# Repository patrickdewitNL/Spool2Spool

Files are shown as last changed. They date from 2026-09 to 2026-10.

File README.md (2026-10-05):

# Spool2Spool Controller

Dual-motor arm/tension controller: an ESP-WROOM-32 devkit driving two 24V geared DC motors
through BTS7960/IBT-2 drivers, with an I2C LCD for local readout/control and a separate
Wemos D1 mini node reading the arm angle right at the pivot.

## What it does

- **Motor 2** has the only encoder (hall sensor/pulse feedback) in the system: closed loop
  constant speed control, targeting a speed in m/min (converted to RPM using the spool
  diameter). Pot 2 sets this target continuously in auto mode, and drives the PWM directly
  (open loop) in manual mode — same knob, different meaning depending on mode. A
  proportional controller corrects the PWM duty once per second.
- **Motor 1** has no encoder of its own. Its baseline PWM continuously tracks motor 2's PWM,
  keeping both motors nominally speed-matched, then gets a small proportional trim based on
  the arm's angle to hold that angle at a live-adjustable target. The angle itself is measured
  by an AS5600 magnetic sensor mounted right at the arm pivot, read by a separate Wemos D1
  mini, and pushed to the ESP32 over a one-way serial link — see
  [Wemos D1 mini angle-sensor node](#wemos-d1-mini-angle-sensor-node) below. The angle trim is
  deliberately small (capped, see `angleTrimLimitPWM`) so a noisy reading right at startup
  can only nudge motor 1 a little, never throw it far from motor 2's PWM. If motor 2's PWM
  is 0 (e.g. a 0 m/min setpoint), motor 1 forces to 0 as well regardless of angle error —
  the trim never applies on top of a stopped motor 2.
- Both motors support **manual override**, driving speed directly from a potentiometer instead
  of the automatic logic.
- Both motor outputs stay at **zero on power-up** until SELECT is pressed once.
- Local UI: LEFT/RIGHT toggle manual/auto mode per motor. A short SELECT press starts the
  system, then (once started) cycles which value UP/DOWN adjusts: spool diameter, then motor
  1's target angle — a transient screen shows the selected value and its new setting each time
  it changes. Motor 2's target speed isn't in this cycle; pot 2 sets that continuously instead
  (see above). Holding SELECT for ~1s while running **stops both motors** and re-arms the start
  interlock (release and press again to restart) — a software convenience stop, not a
  substitute for a real hardware emergency stop, see
  [Machine Directive / CE compliance](#machine-directive--ce-compliance) below. The 20x4 I2C
  LCD otherwise shows a "press SELECT to start" prompt, then live speed/mode2 on the top two
  lines and angle/mode1 on the bottom two.

## Hardware

- ESP-WROOM-32 devkit (30-pin), 3.3V logic throughout
  - ESP mounted using https://www.printables.com/model/1590288-esp32-wroom-32-din-rail-mounting-adapter and https://www.printables.com/model/472505-din-rail-bracket-redux/files
- 20x4 I2C LCD (PCF8574-based backpack, address 0x27)
- 5 discrete pushbuttons (LEFT/RIGHT/UP/DOWN/SELECT), each to GND, using the ESP32's internal
  pull-ups — no external resistors, no resistor-ladder shield
- 2x 24V geared DC motors, each driven through a BTS7960/IBT-2 module (PWM speed control only,
  R_EN/L_EN tied high in hardware, no direction control needed)
- Hall sensor/encoder on motor 2's shaft, 1 pulse per revolution, interrupt driven — the
  only encoder in the system; motor 1 has none
- 2x potentiometers: pot 1 is motor 1's manual PWM override; pot 2 is motor 2's manual PWM
  override in manual mode, and its target speed setpoint in auto mode
- A separate **Wemos D1 mini + AS5600** node mounted at the arm pivot, sending the angle over
  a serial link (see below) — no angle sensor lives on the ESP32 board itself

### EMI

This setup has visible susceptibility to electrical noise, most likely from the BTS7960
drivers' PWM switching and/or from switching on the 230V/24V supply itself:

- Plugging in the 230V/24V supply while the LCD is on has been observed to garble it. The
  firmware now periodically re-inits the LCD controller (`lcdReinitIntervalMs`, every 30s) as
  self-recovery, since a glitch on SDA/SCL can corrupt the PCF8574 backpack's internal state in
  a way plain `lcd.print()` calls don't fix.
- The hall sensor/encoder has shown phantom pulses (read as an implausibly high speed, which
  then yanks motor 2's PWM down hard) — mitigated firmware-side with a debounce
  (`minPulseIntervalMicros`) that drops edges arriving faster than any real pulse could.
- Neither of these firmware mitigations addresses the noise at its source. If it persists,
  hardware measures worth trying: a small RC low-pass filter right at the hall sensor output,
  twisted-pair/shielded wiring for the sensor and I2C runs routed away from the motor power
  leads, decoupling capacitors across the LCD backpack's and BTS7960 modules' supply pins, and
  a proper single-point (star) ground / PE bond for the enclosure.

## Machine Directive / CE compliance

This has two motorized moving parts (the arm and the spools) that can pinch or entangle, which
puts it in scope of the Machine Directive (2006/42/EC — being replaced by Machinery Regulation
(EU) 2023/1230, applicable from January 2027) if it's ever placed on the market rather than kept
as a one-off bench setup. It is **not** currently compliant. The main gap:

- **No emergency stop.** EN ISO 13850 / EN 60204-1 §9.2.5.4 require a readily-accessible
  emergency-stop device (red mushroom-head pushbutton, yellow background, latching/pull-to-release)
  on any machine with a hazard like this. Critically, it must cut power to both motors **in
  hardware** — wired in series with the 24V supply to the BTS7960 drivers (or through a safety
  relay/contactor), not just wired into a GPIO for the firmware to react to. A software-only stop
  (e.g. an E-stop button read like the existing LEFT/RIGHT/UP/DOWN/SELECT buttons, forcing
  `motor1PWM`/`motor2PWM` to 0) doesn't satisfy this: it stops working the moment the ESP32 hangs,
  crashes, is mid-OTA-update, or has a firmware bug — exactly when a hardware stop is needed most.
- This should be a **Category 0 stop** per EN 60204-1 §9.2.2 (immediate removal of power to the
  actuators) — simplest to implement here since these are plain DC motors with no regenerative
  braking or controlled-deceleration requirement.
- After an E-stop trip, the machine must **not** restart on its own when the button is released —
  it needs a deliberate manual reset (e.g. releasing the latch, then pressing SELECT again to
  restart, same as the existing power-up interlock already does).
- The E-stop's own monitoring/status wiring, if any, is the one case in this project's wiring
  where **orange** (EN 60204-1's color for circuits that stay energized with the main switch off)
  would actually apply, rather than the blue used for the ordinary control signals in the tables
  below.

Beyond the E-stop, a full CE Declaration of Conformity would also need a documented risk
assessment (EN ISO 12100) covering the arm/spool pinch points and the other Annex I essential
health and safety requirements — worth doing before this leaves the bench, not just the E-stop
wiring in isolation.

## Pin mapping

| ESP32 pin | Function | Cable color in cabinet | Suggested color (EN 60204-1) |
|---|---|---|---|
| GPIO21 | I2C SDA — LCD | yellow | blue |
| GPIO22 | I2C SCL — LCD | green  | blue |
| GPIO16 | Serial2 RX — angle data in, from the Wemos D1 mini's TX | brown | blue |
| GPIO17 | Serial2 TX — connected to Wemos, not used |  | blue |
| GPIO25 | Motor 1 PWM output (no encoder — tracks motor 2's PWM + arm-angle trim) |  | blue |
| GPIO26 | Motor 2 PWM output (closed loop, driven by the encoder below) |  | blue |
| GPIO4  | Hall sensor / encoder pulse input (interrupt) — measures motor 2's shaft |  | blue |
| GPIO34 | Motor 1 manual override potentiometer (ADC1-only pin) |  | blue |
| GPIO35 | Motor 2 potentiometer — manual override PWM, or target speed setpoint in auto mode (ADC1-only pin) |  | blue |
| GPIO13 | Button: LEFT |  | blue |
| GPIO27 | Button: RIGHT |  | blue |
| GPIO32 | Button: UP |  | blue |
| GPIO33 | Button: DOWN |  | blue |
| GPIO14 | Button: SELECT |  | blue |

Every row above is a DC control-circuit conductor (logic-level signal, not a power feed), which
is why EN 60204-1 puts all of them under the same color — **blue**. The standard reserves other
colors for different roles: **black** for DC/AC power circuit conductors (the +3.3V/5V/GND
supply rails, not any row in this table), **green/yellow** exclusively for the protective earth
(PE) conductor bonded to the enclosure/frame (distinct from logic GND — see the note below), and
**orange** specifically for circuits that must stay energized when the main isolator is off, e.g.
an emergency-stop monitoring loop (see [Machine Directive / CE compliance](#machine-directive--ce-compliance)
below).

Red is always + 3.3V, Black is always GND. Blue is used for 5V from the ESP. Note this cabinet
convention doesn't itself follow EN 60204-1 (which reserves black for power circuits generally,
not GND specifically, and blue for DC control circuits, not a 5V supply feed) — it predates
adding the column above and hasn't been reconciled with it yet.

## Wemos D1 mini angle-sensor node

Firmware: [`software/WemosAngleSensor/WemosAngleSensor.ino`](software/WemosAngleSensor/WemosAngleSensor.ino) —
**finalized**. Reads an AS5600 magnetic angle sensor continuously and sends a line (e.g.
`"123.4\n"`) over its hardware serial only when the angle has moved more than 1 degree since
the last one sent. Purely one-way (Wemos -> ESP32), 9600 baud — nothing is requested or read
back, and the ESP32 side (`software/spool2spool-esp32`) just listens on Serial2 (GPIO16) and
keeps the last value it received.

| Wemos pin | Function | Cable color | Suggested color (EN 60204-1) |
|---|---|---|---|
| D1 (GPIO5) | AS5600 SCL |  | blue (DC control circuit) |
| D2 (GPIO4) | AS5600 SDA |  | blue (DC control circuit) |
| TX | Data out, to the ESP32's GPIO16 (Serial2 RX) |  | blue (DC control circuit) |
| 5V | Power in, from the ESP32 devkit's 5V/VIN pin |  | black (DC power circuit) |
| 3V3 | Powers the AS5600 — not the incoming 5V, keeps the sensor on the same 3.3V rail as the I2C logic |  | black (DC power circuit) |
| GND | Common ground, shared with the ESP32 and the cable shield |  | black (power circuit return — only use green/yellow if this conductor is actually bonded to protective earth, not for a floating logic GND) |

The AS5600's DIR pin ties to GND (or VCC — either works, just don't leave it floating); GPO is
unused since only I2C is needed here.

Cable: simple 4-conductor wire for the ~1.5m run to the arm — one conductor for data, one for
power, one for GND, 1x TX one time RX.

## Libraries

- `Wire.h` — built in
- `LiquidCrystal_I2C` — install via the Arduino Library Manager ("LiquidCrystal I2C"); needs
  a `begin(cols, rows)` variant, e.g. the DFRobot/Marco Schwartz-style fork most Library
  Manager searches return (the WARNING about it claiming "all architectures" is expected and
  harmless on ESP32)
- `WiFi.h`, `WebServer.h` — built in (ESP32 core); back the WiFi dashboard/OTA feature below
- `ElegantOTA` by Ayush Sharma — install via the Arduino Library Manager ("ElegantOTA"); serves
  the browser-based firmware-update page
- `AS5600` by Rob Tillaart — install via the Arduino Library Manager, needed only for the
  **Wemos** sketch, not the ESP32 sketch

## WiFi dashboard & OTA firmware updates

Once the board runs off an external 5V supply instead of USB (see the header comment in
`spool2spool-esp32.ino` for the full rationale), the only way back in is over WiFi:

- **Before flashing**, fill in `wifiSsid`/`wifiPassword` near the top of
  `spool2spool-esp32.ino`. Connecting is best-effort and bounded (10s) — a missing or slow
  network never blocks motor control.
- **Dashboard**: `http://<device-ip>/` mirrors the LCD (live speed/angle, their setpoints,
  motor 1/2 drive % and mode) plus a live graph of speed/angle vs. their setpoints. Graph
  history lives in the *browser's* `localStorage`, not on the ESP32 — it only covers however
  long that tab has been open/polling, isn't shared between browsers/devices, and has a
  "Clear graph history" button to purge it. The graph pulls in Chart.js from a CDN, so the
  *browser* needs internet access to render it (the ESP32 itself only needs the local network).
- **Firmware updates**: `http://<device-ip>/update` (ElegantOTA), also linked as a button from
  the dashboard. Because this is a browser-based updater rather than `ArduinoOTA`, the Arduino
  IDE's own Upload button won't find it as a network port — instead use **Sketch → Export
  Compiled Binary** (compiles without trying to upload anywhere) to produce a `.bin` in the
  sketch folder, then upload that file through the `/update` page.
- **AP fallback**: if the configured network isn't reachable at boot, the ESP32 hosts its own
  access point instead (`Spool2Spool-Setup` / `spool2spool` — change the password in the
  sketch), so the dashboard/OTA page is still reachable at `http://192.168.4.1` even out in the
  field with no WiFi around. This only happens once, at boot — it stays on the fallback AP
  until rebooted, it doesn't keep retrying the configured network in the background.

## Building / flashing

**ESP32 main controller**: open
[`software/spool2spool-esp32/spool2spool-esp32.ino`](software/spool2spool-esp32/spool2spool-esp32.ino)
in the Arduino IDE, select an ESP32 Dev Module board (arduino-esp32 core 3.x — needed for
`analogWrite()` support), install `LiquidCrystal_I2C` and `ElegantOTA`, fill in
`wifiSsid`/`wifiPassword` (see [WiFi dashboard & OTA firmware updates](#wifi-dashboard--ota-firmware-updates)
above), and upload over USB. After this first flash, further updates can go out over OTA
instead — USB is only required once.

**Wemos angle-sensor node**: open
[`software/WemosAngleSensor/WemosAngleSensor.ino`](software/WemosAngleSensor/WemosAngleSensor.ino),
select a Wemos D1 mini (ESP8266) board, install `AS5600`, and upload.

## Configuration

A handful of constants at the top of `spool2spool-esp32.ino` are meant to be tuned on the bench:

- `targetSpeedMPM` — motor 2's target speed in m/min, set continuously from pot 2 while in
  auto mode (see "What it does" above); the value at declaration is just a fallback default
- `Kp` — motor 2's speed-loop gain, currently 4.0. Named `Kp` but functionally an *integral*
  gain: the loop accumulates `Kp * error / 10` into the PWM every cycle rather than setting the
  PWM fresh from the current error each time, so it drives steady-state error to zero given
  enough cycles, at the cost of a slower initial response than true proportional control would
  give — still just a starting guess, keep tuning on the bench
- `maxMotor2PwmStepPerCycle` — caps how much the integral term above can move motor 2's PWM in
  a single ~1s cycle, in either direction. Without this, a big fresh error (e.g. at startup:
  target speed vs. actual 0) integrates into a near-instant slam to a high PWM before the
  motor/spool can physically respond — this smooths that into a gradual ramp instead. Doesn't
  affect the SELECT long-press stop or a real emergency stop, both of which cut power directly
  rather than ramping down through this loop
- `maxSetpointRampMPMPerCycle` — separate from the PWM-side cap above: slews the *setpoint*
  actually fed into the control loop's error calculation up to `targetSpeedMPM` instead of
  jumping straight to it, reset to 0 on every start. Targets startup overshoot specifically —
  even with the PWM step capped, a large fresh error (target vs. actual 0 at startup) stays
  large for several cycles while the motor/feedback catch up, so the integral term keeps adding
  the max step the whole time and has to unwind it afterward. Ramping the setpoint means the
  loop is never handed a big error to wind up against in the first place
- `spoolDiameterMM` — used to convert `targetSpeedMPM` to a target RPM for motor 2, and for
  the m/min display; live-adjustable via UP/DOWN, does not persist across power cycles
- `targetAngleDeg` — motor 1's target arm angle, live-adjustable via UP/DOWN; starting value
  is a placeholder
- `KpAngle` — motor 1's proportional gain for the angle trim; kept deliberately small since
  this is meant to be a fine correction, not the primary driver
- `angleTrimLimitPWM` — caps how far the angle trim can push motor 1 away from motor 2's PWM
- `angleMin` / `angleMax` — the arm's real angle range, placeholders until the real range of
  motion is measured; also clamps `targetAngleDeg` and the incoming `armAngle` reading
- `0x27` (LCD I2C address, in the `lcd()` constructor) — change to `0x3F` if the display stays
  blank, or run an I2C scanner sketch to confirm

On the Wemos side, `changeThresholdDeg` in `WemosAngleSensor.ino` sets how far the angle has to
move before a new reading is sent.

## TODO

Firmware:

- [x] Tune `Kp` (motor 2 speed loop) against the real motor/load once motor 2 is running --
      confirmed working on the bench. Along the way this also surfaced and fixed several real
      bugs beyond tuning: hall-sensor debounce/plausibility filtering (`minPulseIntervalMicros`,
      `maxPlausibleRpmJumpFactor`), integer-truncation steady-state offset (`motor2PWMF`), pot
      setpoint noise (`pot2Filtered`), and startup overshoot (`maxMotor2PwmStepPerCycle`,
      `maxSetpointRampMPMPerCycle`) -- see [Configuration](#configuration) for all of these
- [ ] Tune `KpAngle` and `angleTrimLimitPWM` (motor 1's angle trim) on the bench
- [ ] Set `angleMin`/`angleMax` from the arm's actual range of motion, and pick a sensible
      starting `targetAngleDeg` within that range
- [ ] Confirm the AS5600's mounting orientation on the arm matches the sign/direction expected
      by `angleMin`/`angleMax` (`setDirection()` in `WemosAngleSensor.ino` flips it if needed)
- [ ] Button debounce is edge-detection only, no time-based debounce yet
- [ ] Both motors' correction loops run once per second; may need a shorter interval if RPM or
      angle swings under real load correct too slowly
- [ ] Option: give motor 1 its own encoder for real closed-loop RPM feedback, instead of
      tracking motor 2's PWM + angle trim. A free interrupt-capable GPIO is available for
      this (e.g. GPIO18) — same pattern as the existing encoder (`INPUT_PULLUP` +
      `attachInterrupt(..., FALLING)`). Not started yet.
- [ ] Real compile verification of `spool2spool-esp32.ino` via arduino-cli is still outstanding —
      blocked so far by a network policy restriction, not yet re-attempted

Hardware / compliance:

- [ ] Add a hardware emergency stop (Category 0, EN ISO 13850 / EN 60204-1 §9.2.5.4) wired
      directly in series with the 24V supply to both BTS7960 drivers, not just a GPIO the
      firmware reads — see [Machine Directive / CE compliance](#machine-directive--ce-compliance)
- [ ] Document a risk assessment (EN ISO 12100) covering the arm/spool pinch points before this
      leaves the bench
- [ ] Track down the EMI source (see the [EMI](#emi) note above) with hardware measures --
      firmware-side debounce/re-init are mitigations, not a fix

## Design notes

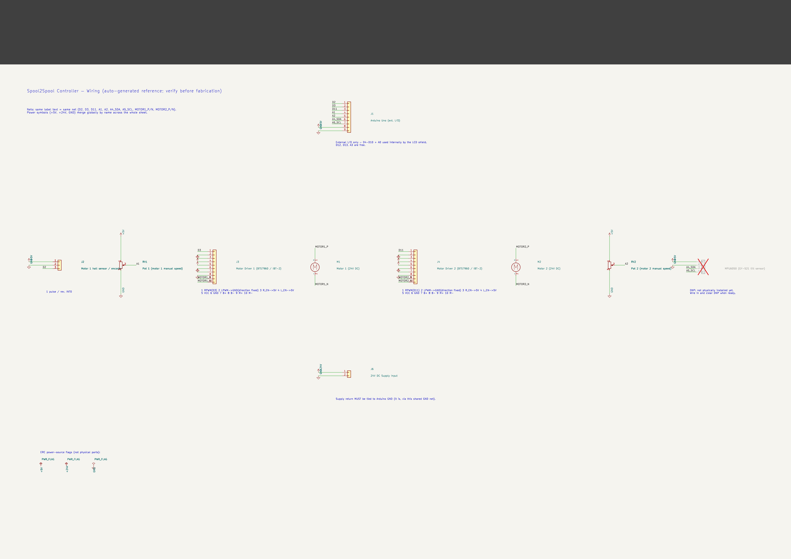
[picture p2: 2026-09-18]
hardware/kicad/schematic.png

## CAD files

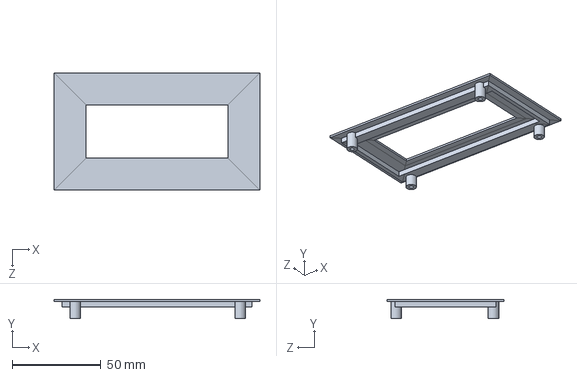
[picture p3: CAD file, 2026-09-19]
hardware/Screen-bezel/bezel-screen.SLDASM
116.0 x 10.7 x 66.0 mm

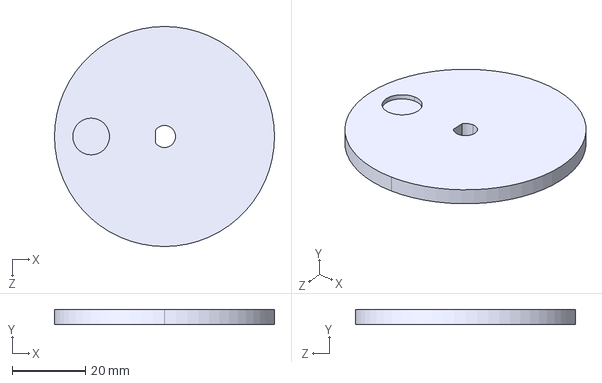
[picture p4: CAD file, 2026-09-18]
hardware/encoder-disk/encoder-disk-20mm.STEP
60.0 x 4.00 x 60.0 mm

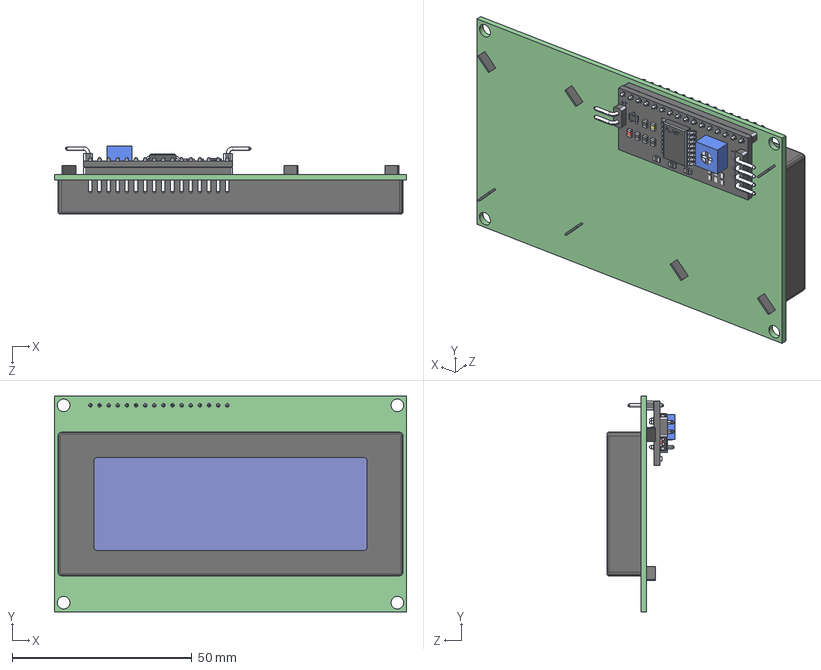
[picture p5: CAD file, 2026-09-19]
hardware/Screen-bezel/lcd-20x4-i2c-1.snapshot.4/Lcd i2c.STEP
98.0 x 60.0 x 19.0 mm
20x4 LCD
I2C LCD Adapter PCF8574
2 way header curved
4 way header curved

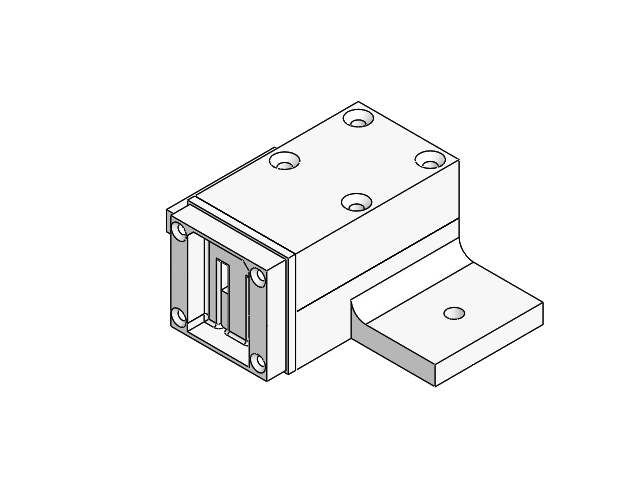
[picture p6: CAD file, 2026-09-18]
hardware/angle-sensor/angle-sensor-assembl.SLDASM
angle-sensor-bottom
AS5600

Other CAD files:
hardware/angle-sensor/PRODUCT_13_ASM_2_ASM.SLDASM
hardware/Screen-bezel/Lcd i2c.SLDASM
hardware/angle-sensor/SOT23-5_001_ASM_1_ASM.SLDASM
hardware/Screen-bezel/Assem1.SLDASM
hardware/angle-sensor/WEMOS-D1-MINI_STEP_1_ASM_2_ASM.SLDASM
hardware/angle-sensor/SOIC-16_150MIL_001_ASM_1_ASM.SLDASM
hardware/angle-sensor/WEMOS-MINI-D1_ASM.SLDASM
hardware/angle-sensor/ASSEMBLY-1225_ASM_1_ASM.SLDASM
hardware/angle-sensor/WEMOS-MINI-D1_ASM_2_ASM.SLDASM
hardware/angle-sensor/ASSEMBLY-1002_ASM_1_ASM.SLDASM
hardware/angle-sensor/ASSEMBLY-1505_ASM_1_ASM.SLDASM
hardware/angle-sensor/SOT23_ASM_1_ASM.SLDASM
hardware/angle-sensor/SOT23_2_1.SLDPRT
hardware/Screen-bezel/screen-bezel.SLDPRT
hardware/Screen-bezel/2 way header curved.SLDPRT
hardware/Screen-bezel/20x4 LCD.SLDPRT
hardware/Screen-bezel/4 way header curved.SLDPRT
hardware/Screen-bezel/I2C LCD Adapter PCF8574.SLDPRT
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

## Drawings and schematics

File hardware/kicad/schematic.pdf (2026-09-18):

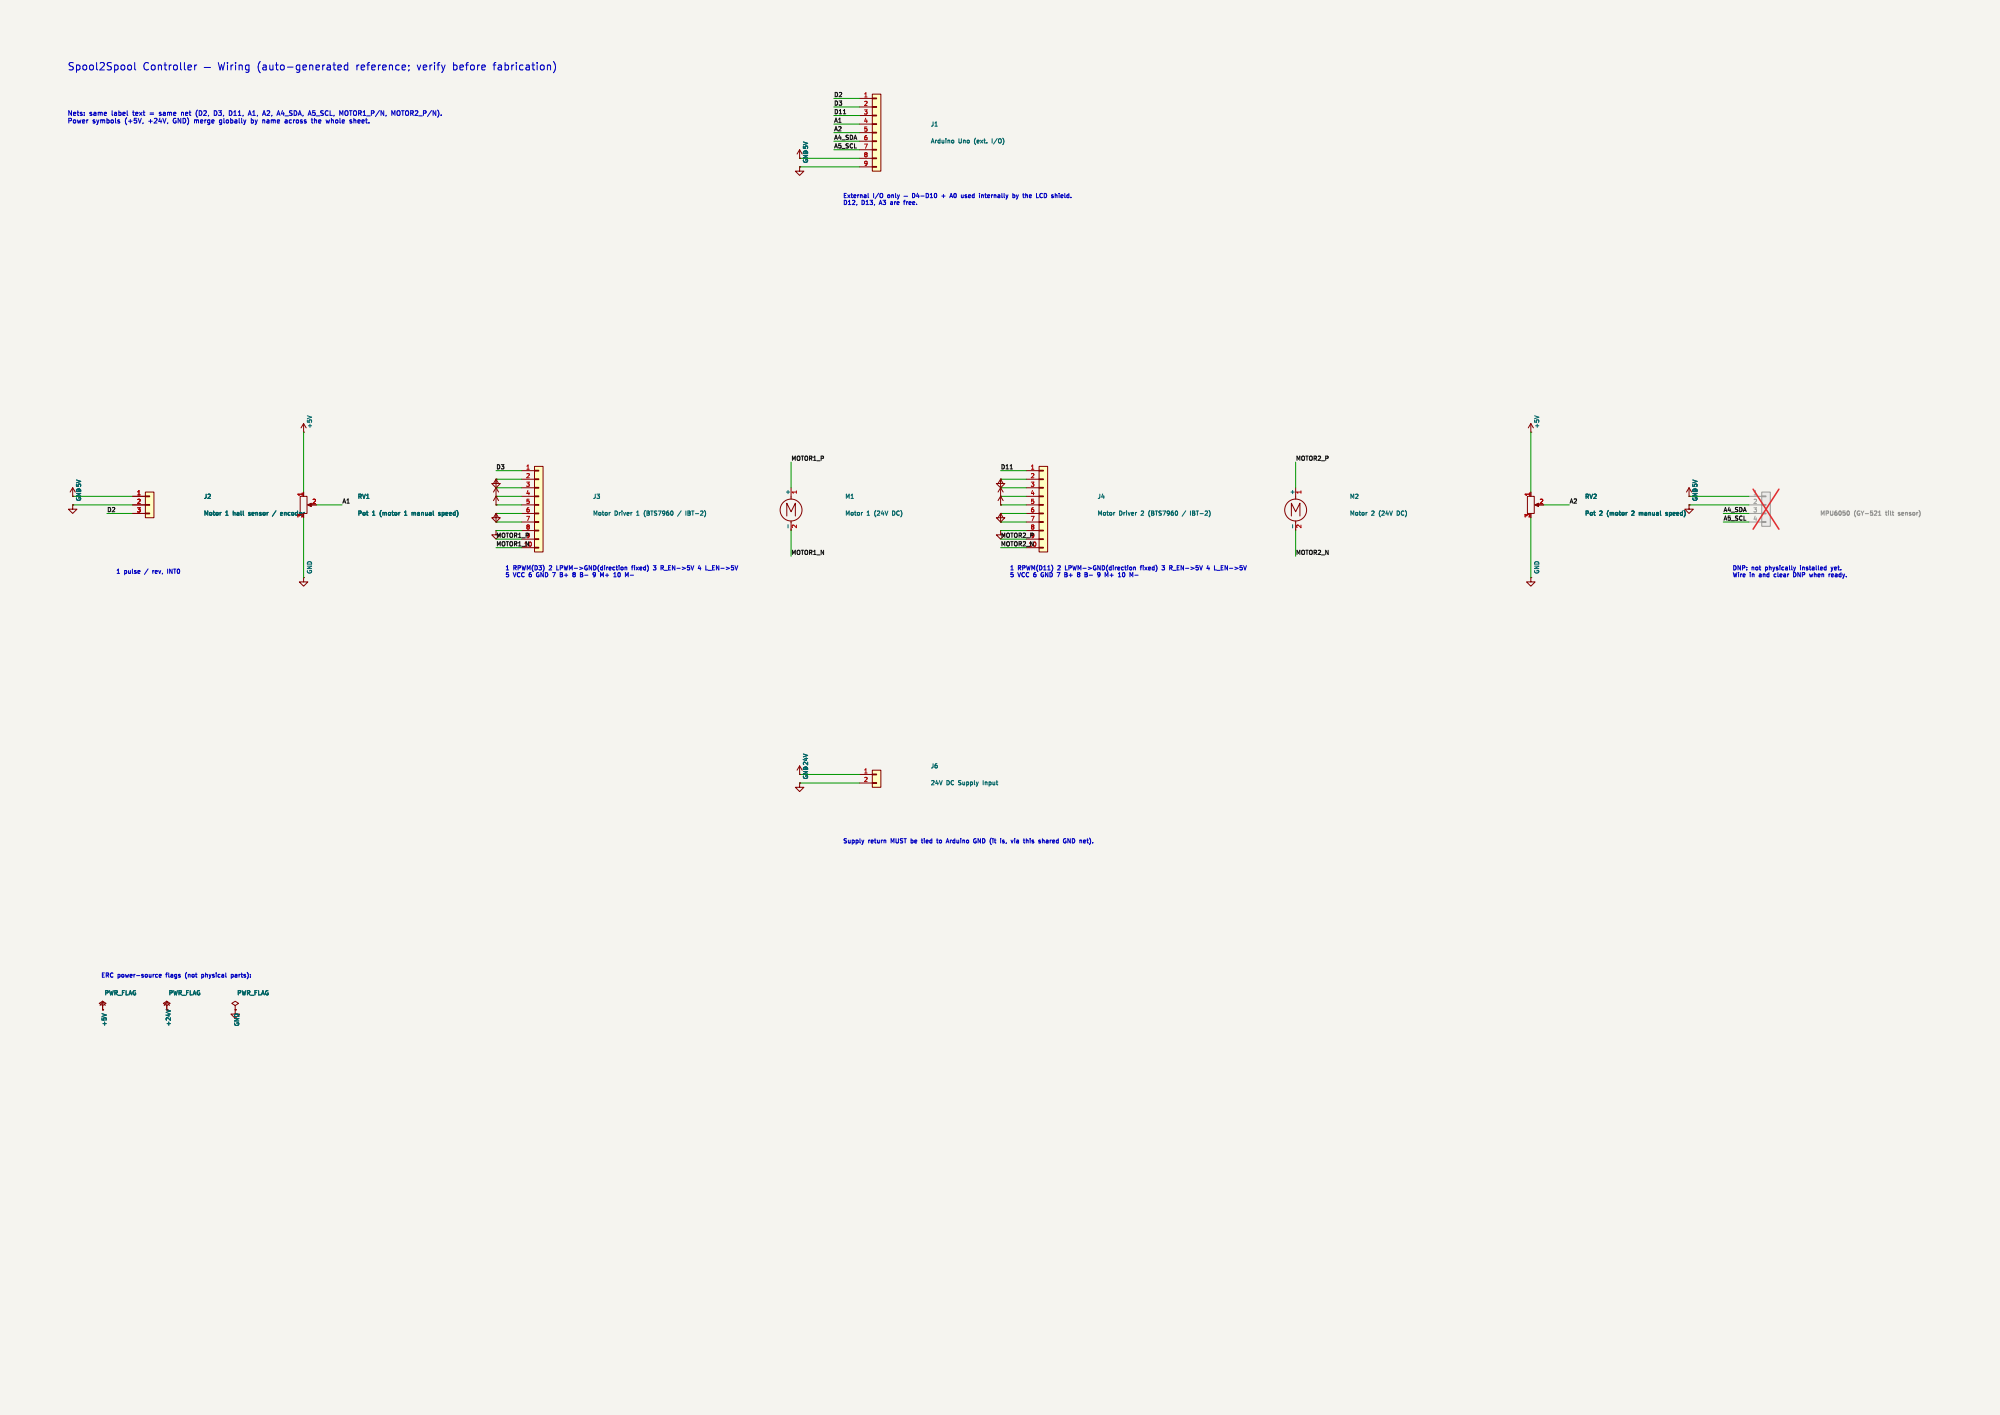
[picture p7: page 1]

RV2 Pot 2 (motor 2 manual speed) 1 3

5 VCC 6 GND 7 B+ 8 B- 9 M+ 10 M- Supply return MUST be tied to Arduino GND (it is, via this shared GND net).

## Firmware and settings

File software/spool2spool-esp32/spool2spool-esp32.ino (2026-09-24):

/*
  Dual motor control, ESP32 (30-pin devkit) + I2C 20x4 LCD
  Ported from software/spool2spool-arduino/spool2spool-arduino.ino — same control
  logic and behavior, retargeted for the ESP32 + I2C LCD, with 5 discrete buttons
  replacing the DFRobot shield's analog button ladder (that ladder doesn't exist
  without the shield; the button/keypad approach was still open in the README TODO,
  discrete GPIOs is the simplest default and easy to swap for an I2C keypad later).

  - Motor 2 has the only encoder/hall sensor: closed loop constant speed control, target
    set live as a speed in m/min (converted to RPM via the spool diameter). Pot 2 sets this
    target speed continuously in auto mode, and drives the PWM directly (open loop) in
    manual mode -- same knob, same feel, different meaning depending on mode.
  - Motor 1 has no encoder of its own, so its baseline PWM continuously tracks motor 2's
    PWM (keeping both motors nominally speed-matched), fine-tuned by a small proportional
    correction based on the arm angle -- received over Serial2 from the Wemos D1 mini
    angle-sensor node (software/WemosAngleSensor — AS5600 next to the arm pivot) -- holding
    that angle at a live-adjustable target. The angle term is deliberately a small trim on
    top of the motor-2-tracking baseline, not the primary driver: the angle reading is
    noisy/unreliable right at startup, so a bad first reading can only nudge motor 1 a
    little, never throw it far from motor 2's PWM.
  - Buttons: LEFT/RIGHT toggle manual/auto mode per motor. SELECT starts the system, then
    (once started) a short press cycles what UP/DOWN adjusts: spool diameter, then motor 1's
    target angle. Holding SELECT for ~1s while running stops both motors and re-arms the start
    interlock (a software convenience stop, not a substitute for a real hardware emergency
    stop -- see the README's "Machine Directive / CE compliance" section).
  - Both motor outputs stay at zero after power up until SELECT is pressed once, and again
    after a SELECT long-press stop until it's pressed again
  - LCD shows an "EMI Twente" splash screen at boot, then a "press SELECT to start" prompt,
    then live speed/angle/mode

  Wiring (30-pin ESP32 devkit):
  - LCD SDA -> GPIO21, LCD SCL -> GPIO22 (default I2C — LCD is the only I2C device on this  groen/geel
    board now)
  - Serial2 RX -> GPIO16, from the Wemos D1 mini's TX (one-way link — this board's TX/GPIO17  
    is unused, the Wemos never listens)
  - motor1PwmPin -> GPIO25 (motor 1 driver RPWM)  paars 
  - motor2PwmPin -> GPIO26 (motor 2 driver RPWM) paars
  - encoderPin    -> GPIO4  (hall sensor / encoder, interrupt capable — any GPIO works on ESP32)  oranje
  - pot1Pin -> GPIO34, grijs
  - pot2Pin -> GPIO35 (ADC1-only pins — avoids ADC2/WiFi conflicts) grijs

  - buttons -> GPIO13 (LEFT), GPIO27 (RIGHT), GPIO32 (UP), GPIO33 (DOWN), GPIO14 (SELECT),
    each wired to GND through a pushbutton, using the internal pull-up (no external resistors)

  Libraries needed:
  - Wire.h                 (built in)
  - LiquidCrystal_I2C.h    (install via Library Manager, search "LiquidCrystal I2C" — needs
    a begin(cols, rows) variant, e.g. the one bundled with the DFRobot/Marco Schwartz-style
    fork most Library Manager searches return; default I2C address assumed 0x27 below,
    change if your backpack uses 0x3F, or run an I2C scanner sketch if the display stays blank)
  - WiFi.h, WebServer.h    (built in)
  - ElegantOTA.h           (install via Library Manager, search "ElegantOTA" by Ayush Sharma)

  Requires arduino-esp32 core 3.x — that's what gives analogWrite() direct PWM support here,
  same call signature as the original AVR code. Older cores need ledcWrite() instead.

  WiFi / OTA / web dashboard:
  - Once this board runs off an external 5V supply instead of USB, wifiSsid/wifiPassword below
    must be filled in before flashing -- that's the only way to reach it afterwards.
  - The web page at http://<device-ip>/ mirrors the LCD (speed, angle, motor %, modes) plus a
    live graph; firmware updates happen from the browser at http://<device-ip>/update
    (ElegantOTA), no Arduino IDE or USB needed.
  - The graph's history lives in the browser's localStorage, not on the ESP32 -- it only
    accumulates while that browser tab has been polling, resets if you clear site data, and
    isn't shared between browsers/devices viewing the page.
  - The dashboard's Chart.js is loaded from a CDN, so the *browser* needs internet access to
    render the graph (the ESP32 itself only needs to be on the same LAN, no internet required).
  - WiFi connection is best-effort and never blocks motor control: it times out after 10s at
    boot if not connected -- the motors run with or without WiFi.
  - AP fallback: if the configured network isn't reachable at boot, the device becomes its own
    WiFi access point (apSsid/apPassword below) instead of being unreachable -- connect a phone
    or laptop to it and the same dashboard/OTA page is at http://192.168.4.1 (ESP32's default
    AP address). This is the way to push a firmware fix out in the field with no WiFi around.
    It only kicks in once, at boot -- if it falls back to AP, it stays on AP until rebooted, it
    doesn't keep trying the configured network in the background afterwards.
*/

#include <Wire.h>
#include <LiquidCrystal_I2C.h>
#include <WiFi.h>
#include <WebServer.h>
#include <ElegantOTA.h>
#include "dashboard_html.h"

// ---- I2C LCD ----
// address 0x27 is the common default for PCF8574-based backpacks; some use 0x3F instead
LiquidCrystal_I2C lcd(0x27, 20, 4);

// ---- WiFi / OTA / web dashboard ----
// fill these in before flashing -- see header comment above for what this enables. Not
// secret enough to warrant anything fancier than living here, this device never leaves a
// private network.
const char *wifiSsid = "VerkeerdVerbonden";
const char *wifiPassword = "welkomopzuiderzee663";
const unsigned long wifiConnectTimeoutMs = 10000;  // best-effort at boot, never blocks longer than this

// AP fallback -- if wifiSsid isn't reachable at boot, the device hosts this network itself
// instead, so the dashboard/OTA page is always reachable somehow. WPA2-protected since this
// AP exposes the /update firmware page to whoever joins it -- change the password below.
const char *apSsid = "Spool2Spool-Setup";
const char *apPassword = "spool2spool";  // WPA2 needs >= 8 chars

WebServer server(80);
bool otaReady = false;  // true once server.begin()/ElegantOTA.begin() have run (STA or AP)

// ---- Motor pins ----
const int motor1PwmPin = 25;  // motor 1, no encoder -- tracks motor 2's PWM, fine-tuned by arm angle
const int motor2PwmPin = 26;  // motor 2, closed loop RPM control (this motor has the encoder)

// ---- Encoder / hall pulse pin (motor 2 speed feedback -- the only encoder in this system) ----
const int encoderPin = 4;     // interrupt capable — any GPIO works on ESP32
volatile unsigned long pulseCount = 0;          // lifetime count, diagnostics only
volatile unsigned long lastPulseMicros = 0;     // micros() at the most recent *accepted* pulse
volatile unsigned long pulsePeriodMicros = 0;   // time between the last two accepted pulses
// no pulse for this long -> treat as stopped rather than let the RPM estimate decay forever
const unsigned long stalledTimeoutMicros = 10000000UL;  // 10s, ~2x the slowest expected pulse interval
// debounces the hall sensor -- an open-collector output sitting right next to a PWM motor
// driver is prone to noise glitches (mechanical contact bounce, or the driver's switching
// coupling into the sensor wire), each of which reads as an extra FALLING edge and spikes the
// computed RPM way past reality, which then yanks the speed loop's PWM down hard for a step
// (see loop() below) -- looks like "speed fluctuates and the motor randomly stops". A genuine
// pulse can't arrive faster than ~94ms even in the fastest realistic case (10 m/min on the
// smallest 5mm spool, 1 pulse/rev -> ~637 RPM); anything closer together than this is treated
// as noise and dropped, not counted as a real pulse.
const unsigned long minPulseIntervalMicros = 10000UL;  // 10ms -- well under the ~94ms fastest
                                                         // realistic pulse, well above typical
                                                         // bounce/EMI glitch duration
unsigned long lastCalcTime = 0;
float currentRPM = 0;
float currentLinearSpeed = 0;  // m/min, derived from the smoothed RPM and spoolDiameterMM, for display only

// ---- RPM plausibility filter -- catches noise the debounce above can't. minPulseIntervalMicros
// only rejects edges arriving implausibly fast (sub-10ms bounce); it does nothing about a noise
// pulse landing tens or hundreds of ms after a real one, well above that floor but still far
// too soon for a genuine revolution at the current speed (seen on the bench: RPM jumping
// ~51 -> 189 -> ~48 in consecutive 1s samples, which this motor/spool cannot physically do --
// a real reading can't be several times the recent trend in a single update). Readings more
// than maxPlausibleRpmJumpFactor times the last *accepted* RPM are treated as noise and
// discarded (reusing the last accepted value for that cycle) instead of feeding the averages
// or the control loop.
//
// Only ever holds a reading back for maxConsecutiveRejections cycles, not indefinitely: if
// lastAcceptedRPM simply never updated again once a reading was rejected, a *genuine* fast
// change (ramp-up from a stop, a setpoint jump) would permanently freeze it at a stale low
// value -- and since the control loop below compares the target against that frozen number,
// it keeps reading a huge error and cranks motor2PWM toward max forever trying to close a gap
// that can never close, while the real (unreported) speed runs away. Seen on the bench. A
// second consecutive implausible reading is far more likely to be a genuine change than two
// coincidental noise spikes in a row, so it's accepted outright rather than held again.
float lastAcceptedRPM = 0;
int consecutiveRejectedRPM = 0;
const float maxPlausibleRpmJumpFactor = 1.5;  // tune down if real glitches still get through,
                                                // up if genuine fast accelerations start
                                                // getting held back
const int maxConsecutiveRejections = 1;        // hold back this many implausible readings in a
                                                 // row before giving up and accepting the latest

// ---- Speed display smoothing ----
// display only (LCD/dashboard/serial) -- deliberately heavier than the control-loop smoothing
// below, since a slow-moving display reading is fine but a slow-reacting P-loop isn't.
const int speedAvgSamples = 5;  // ~5 seconds of smoothing at the once-per-second update rate
float speedAvgBuffer[speedAvgSamples] = {0};
int speedAvgIndex = 0;
int speedAvgCount = 0;  // samples recorded so far, caps at speedAvgSamples

// ---- Speed control-loop smoothing ----
// a single one-pulse-per-rev period reading is inherently noisy (cogging, gear backlash,
// pulse-timing quantization) even with the hall sensor's debounce above catching genuinely
// spurious pulses -- feeding that raw noise straight into the *additive* P-loop below
// (motor2PWM += ...) every second was pushing the motor around on every noisy reading. This
// is a separate, lighter average than the display's (controlAvgSamples vs. speedAvgSamples):
// short enough that the loop still reacts to a real speed change (setpoint turn, load change)
// within a couple of seconds, not the display's ~5s.
const int controlAvgSamples = 3;
float controlAvgBuffer[controlAvgSamples] = {0};
int controlAvgIndex = 0;
int controlAvgCount = 0;

// ---- Potentiometers ----
const int pot1Pin = 34;  // motor 1 manual speed (ADC1-only pin)
const int pot2Pin = 35;  // motor 2: manual PWM in manual mode, target speed setpoint in
                          // auto mode -- same knob, different meaning (ADC1-only pin)

// ---- Pot 2 smoothing -- the ESP32 ADC has a few LSBs of read noise on its own, which
// otherwise jitters targetSpeedMPM (and the PWM it maps to in manual mode) on every loop()
// pass even with the pot held dead still. Exponential moving average, updated every loop --
// potEmaAlpha trades responsiveness for smoothness: lower = smoother but slower to follow a
// real knob turn.
float pot2Filtered = -1;  // -1 = not seeded yet, see loop()
const float potEmaAlpha = 0.05;

// ---- Buttons (discrete GPIOs, internal pull-up, pressed = LOW) ----
const int btnLeftPin   = 13;
const int btnRightPin  = 27;
const int btnUpPin     = 32;
const int btnDownPin   = 33;
const int btnSelectPin = 14;

// ---- Start interlock, both motor outputs stay at zero until SELECT is pressed once ----
bool started = false;
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
void loop() {
  updateArmAngleFromSerial();  // non-blocking; keeps armAngle fresh whenever the Wemos sends

  // ---- periodic LCD re-init -- self-recovery from I2C glitches, see lastLcdReinit above ----
  if (millis() - lastLcdReinit > lcdReinitIntervalMs) {
    lcd.begin(20, 4);
    lcd.backlight();
    lastLcdReinit = millis();
  }

  // ---- dashboard/OTA request handling -- setup() always leaves the server running, on
  // either the configured network or the fallback AP, so this is unconditional. Reachable
  // even before SELECT is pressed, deliberately ahead of the !started early-return below. ----
  server.handleClient();
  ElegantOTA.loop();

  // ---- both outputs stay at zero until SELECT has been pressed once ----
  if (!started) {
    int startBtn = readLCDButton();
    // after a long-press stop (below), SELECT is still physically held -- don't let that same
    // press instantly restart it, wait for it to be released at least once first
    if (waitForSelectRelease && startBtn != 4) {
      waitForSelectRelease = false;
    }
    if (!waitForSelectRelease && startBtn == 4) {  // SELECT
      started = true;
      lastButton = startBtn;
      // this press is already down right now -- start the long-press-stop timer fresh from
      // this moment, otherwise a stale timestamp from a previous stop could re-trigger it
      // on the very press that just started the system
      selectPressedSinceMillis = millis();
      selectStopFired = false;
      rampedTargetSpeedMPM = 0;  // soft-start the setpoint fresh on every start, not just the
                                  // very first one -- see maxSetpointRampMPMPerCycle above
      // motor2PWMF/motor2PWM otherwise still hold setup()'s one-time seed from wherever pot 2
      // happened to be at boot (or whatever they were at the last stop) -- that gets written
      // to the pin instantly the moment `started` flips true, completely bypassing the ramp
      // above, which only limits how fast the *correction* changes PWM, not this baseline.
      // Reset both to 0 here so the very first PWM after a start is actually 0, not a jump.
      motor2PWMF = 0;
      motor2PWM = 0;
      analogWrite(motor2PwmPin, 0);
      lcd.clear();
      Serial.println("SELECT pressed -- started");
    } else {
      analogWrite(motor1PwmPin, 0);
      analogWrite(motor2PwmPin, 0);
      if (millis() - lastLcdUpdate > 250) {
        lcdPrintLine(1, "Press SELECT to");
        lcdPrintLine(2, "start");
        lastLcdUpdate = millis();
      }
      if (millis() - lastWaitingDebug > 2000) {
        Serial.println("Waiting for SELECT (GPIO14 pulled LOW) -- if buttons aren't wired "
                        "yet, this is expected and will just sit here");
        lastWaitingDebug = millis();
      }
      return;  // skip mode/angle/motor logic entirely until started
    }
  }

  // ---- read buttons, act on new press only ----
  int btn = readLCDButton();

  // ---- SELECT held for selectStopHoldMs -- stop both motors, independent of the short-press
  // cycle-adjust-target action below. Must return immediately: motor2/motor1 PWM further down
  // get re-driven every loop from the pots in manual mode, so just zeroing them here and
  // falling through would have them immediately overwritten this same iteration. ----
  if (btn == 4) {
    if (selectPressedSinceMillis == 0) selectPressedSinceMillis = millis();
    if (!selectStopFired && millis() - selectPressedSinceMillis >= selectStopHoldMs) {
      selectStopFired = true;
      waitForSelectRelease = true;
      started = false;
      analogWrite(motor1PwmPin, 0);
      analogWrite(motor2PwmPin, 0);
      lcd.clear();
      Serial.println("SELECT held -- both motors stopped, release SELECT to re-arm");
      lastButton = btn;
      return;
    }
  } else {
    selectPressedSinceMillis = 0;
    selectStopFired = false;
  }

  if (btn != -1 && btn != lastButton) {
    if (btn == 3) manualMode1 = !manualMode1;  // LEFT toggles motor 1 mode
    if (btn == 0) manualMode2 = !manualMode2;  // RIGHT toggles motor 2 mode

    if (btn == 4) {  // SELECT (after start): cycle which value UP/DOWN adjusts
      adjustTarget = (adjustTarget + 1) % 2;
      adjustDisplayUntil = millis() + adjustDisplayDuration;
    }

    if (btn == 1) {  // UP
      if (adjustTarget == 0) {
        spoolDiameterMM = min(spoolDiameterMM + spoolDiameterStepMM, spoolDiameterMaxMM);
      } else {
        targetAngleDeg = min(targetAngleDeg + angleStepDeg, angleMax);
      }
      adjustDisplayUntil = millis() + adjustDisplayDuration;
    }
    if (btn == 2) {  // DOWN
      if (adjustTarget == 0) {
        spoolDiameterMM = max(spoolDiameterMM - spoolDiameterStepMM, spoolDiameterMinMM);
      } else {
        targetAngleDeg = max(targetAngleDeg - angleStepDeg, angleMin);
      }
      adjustDisplayUntil = millis() + adjustDisplayDuration;
    }
  }
  lastButton = btn;

  // ---- motor 2: manual pot drives PWM directly, auto pot sets the target speed instead ----
  int potVal2Raw = analogRead(pot2Pin);
  if (pot2Filtered < 0) pot2Filtered = potVal2Raw;  // seed on the very first read, no ramp-in
  pot2Filtered += potEmaAlpha * (potVal2Raw - pot2Filtered);
  int potVal2 = (int)(pot2Filtered + 0.5f);
  if (manualMode2) {
    motor2PWM = map(potVal2, 0, 4095, 255, 0);  // inverted: potVal 0 = full, 4095 = stop. ESP32 ADC is 12-bit (0-4095), not 10-bit like AVR
    motor2PWMF = motor2PWM;  // keep the float accumulator in sync so switching back to auto
                              // continues smoothly from here, not a stale pre-manual value
    analogWrite(motor2PwmPin, motor2PWM);
  } else {
    // same inverted feel as manual mode: 0 = max target speed, 4095 = stop
    targetSpeedMPM = speedMaxMPM - (speedMaxMPM - speedMinMPM) * (potVal2 / 4095.0);
  }

  // ---- motor 1: manual pot override (auto = tracks motor 2's PWM + arm-angle trim, below) ----
  if (manualMode1) {
    int potVal1 = analogRead(pot1Pin);
    motor1PWM = map(potVal1, 0, 4095, 255, 0);  // inverted: potVal 0 = full, 4095 = stop. ESP32 ADC is 12-bit (0-4095), not 10-bit like AVR
    analogWrite(motor1PwmPin, motor1PWM);
  }

  if (millis() - lastCalcTime >= 1000) {
    noInterrupts();
    unsigned long period = pulsePeriodMicros;
    unsigned long lastPulse = lastPulseMicros;
    interrupts();

    unsigned long sinceLastPulse = micros() - lastPulse;

    if (lastPulse == 0 || sinceLastPulse > stalledTimeoutMicros) {
      // no pulse yet, or it's been way longer than a normal interval -> genuinely stopped
      currentRPM = 0;
    } else {
      // use whichever is longer: the last measured interval, or how long it's been since
      // that pulse — so the estimate keeps easing down every second if the shaft is
      // slowing, instead of freezing at the last (higher) reading until the next pulse
      unsigned long effectivePeriod = max(period, sinceLastPulse);
      currentRPM = 60000000.0 / effectivePeriod;  // change multiplier if more than 1 pulse per rev
    }

    // plausibility filter -- see lastAcceptedRPM/maxPlausibleRpmJumpFactor above. Only guards
    // against an implausible *increase*; a drop (including to 0, a genuine stop) always passes
    // straight through, no jump-factor check needed on that side, and always resets the
    // rejection streak.
    bool implausible = lastAcceptedRPM > 1.0 && currentRPM > lastAcceptedRPM * maxPlausibleRpmJumpFactor;
    if (implausible && consecutiveRejectedRPM < maxConsecutiveRejections) {
      consecutiveRejectedRPM++;
      Serial.print("Holding implausible RPM reading (");
      Serial.print(consecutiveRejectedRPM);
      Serial.print(" in a row): ");
      Serial.print(currentRPM);
      Serial.print(" (last accepted ");
      Serial.print(lastAcceptedRPM);
      Serial.println(")");
      currentRPM = lastAcceptedRPM;  // reuse the last good reading this cycle instead
    } else {
      lastAcceptedRPM = currentRPM;
      consecutiveRejectedRPM = 0;
    }

    // moving average over the last speedAvgSamples RPM readings, smooths the displayed
    // speed so it eases toward 0 instead of snapping there the instant pulses stop
    speedAvgBuffer[speedAvgIndex] = currentRPM;
    speedAvgIndex = (speedAvgIndex + 1) % speedAvgSamples;
    if (speedAvgCount < speedAvgSamples) speedAvgCount++;

    float rpmSum = 0;
    for (int i = 0; i < speedAvgCount; i++) rpmSum += speedAvgBuffer[i];
    float avgRPM = rpmSum / speedAvgCount;

    currentLinearSpeed = avgRPM * PI * (spoolDiameterMM / 1000.0);  // m/min, smoothed
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

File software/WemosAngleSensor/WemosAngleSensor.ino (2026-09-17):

/*
  Spool2Spool Controller — Wemos D1 mini angle-sensor node (AS5600)
  Reads the AS5600 continuously and actively pushes a new angle reading
  over Serial whenever it changes by more than 1 degree since the last
  one sent — no request/response, no polling from the receiving end,
  this board sends updates on its own initiative.

  Swapped from an MPU6050-based request/response node to this AS5600
  active-push one — see git history for the previous version if the
  MPU6050 approach is still wanted.

  Wiring:
  - AS5600 VCC -> this board's 3V3 pin (most AS5600 breakouts handle
    3.3-5V fine; 3.3V keeps everything on one logic rail)
  - AS5600 GND -> GND
  - AS5600 SCL -> D1 (GPIO5)
  - AS5600 SDA -> D2 (GPIO4)
  - AS5600 DIR -> GND (hardware direction pin — tie to GND or VCC,
    doesn't matter which, just don't leave it floating)
  - AS5600 GPO -> not connected (I2C only)
  - RX/TX (hardware UART) -> ESP32 TX/RX
  - 5V / GND -> power from the ESP32 side over the shared cable

  Protocol:
  - Sends a line like "123.4\n" whenever the angle has moved more than
    1 degree since the last line sent — nothing is sent otherwise
  - Purely one-way (this board -> ESP32). If the ESP32 ever needs to
    ask for a reading on demand instead of just listening for pushes,
    that's a different scheme than this one.

  Library needed:
  - AS5600 by Rob Tillaart (install via Library Manager, search "AS5600")
*/

#include <Wire.h>
#include "AS5600.h"

AS5600 as5600;  // standard AS5600, not the AS5600L variant — swap the class if yours is an L

const float changeThresholdDeg = 1.0;
const long serialBaud = 9600;  // kept modest for noise margin over the long cable run

float lastSentAngle = -1000;  // far outside any real angle, guarantees the first reading gets sent

void setup() {
  Serial.begin(serialBaud);
  delay(500);

  Wire.begin(D2, D1);  // SDA, SCL

  as5600.begin();
  as5600.setDirection(AS5600_CLOCK_WISE);  // arbitrary but explicit; just needs to stay consistent

  if (!as5600.isConnected()) {
    Serial.println("AS5600 NOT connected - check wiring");  // only visible over USB during bench setup
  }
}

void loop() {
  float angle = as5600.readAngle() * AS5600_RAW_TO_DEGREES;

  // note: a change spanning the 0/360 wrap point reads as a large jump here, which still
  // correctly triggers a send — it just doesn't take the shorter way around the circle
  // into account. Not worth the extra complexity unless that turns out to matter in practice.
  if (abs(angle - lastSentAngle) > changeThresholdDeg) {
    Serial.println(angle, 1);
    lastSentAngle = angle;
  }

  delay(50);  // plenty fast to catch a 1-degree change on a slow-moving shaft, without hammering I2C
}

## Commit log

2026-09-11 Initial commit: dual motor boom controller sketch, README, gitignore
    Arduino Uno sketch controlling two 24V motors (closed-loop RPM on
    motor 1, angle-follow on motor 2) via a DFRobot LCD Keypad Shield.
2026-09-11 Use shield SELECT button for start interlock instead of pin 12
2026-09-11 Remove button debug print, keep tuned shield thresholds
2026-09-13 Move manual override pots to A2/A3, add pot/PWM values to serial log
    Pin 2's interrupt line was found wired to TX during bench testing, not
    a firmware issue; pot pins moved to A2/A3 as part of that same wiring
    pass, freeing A1. README pin table and free-pin list updated to match.
2026-09-13 Measure motor 1 speed by inter-pulse period instead of pulses-per-second
    At the expected ~1 pulse per 5-6s, counting pulses in a fixed 1-second
    window mostly just measures 0-or-1, so the reading bounced between 0
    and 60 RPM depending on timing luck. Timing the interval between pulses
    instead gives a real estimate, and easing that estimate down using time
    elapsed since the last pulse (capped by a stall timeout) means it decays
    smoothly rather than freezing until the next pulse arrives. The existing
    moving-average display smoothing sits on top of this, unchanged.
2026-09-14 Document planned controller migration to ESP-WROOM-32 + I2C LCD
    Parts ordered: ESP-WROOM-32 (replaces the Uno) with an I2C LCD, plus a
    Wemos D1 mini mounted right next to the MPU6050 to keep I2C short and
    relay the angle back instead of running I2C 1.5m alongside the motor
    driver wiring. Firmware not migrated yet; README now flags the current
    Uno+shield sections as the existing implementation, not the target.
2026-09-14 Document the Wemos D1 mini angle-sensor node and add first-draft firmware
    Bidirectional serial decided over WiFi/ESP-NOW: simpler, and both the
    Wemos and ESP32 are 3.3V so no level shifting either way. README now
    has the pin layout, request/response protocol, and cable/grounding
    notes for the ~1.5m run. WemosAngleSensor.ino is a first draft, not
    yet bench-tested.
2026-09-17 Switch Wemos angle-sensor node from MPU6050 to AS5600
    Finalized: reads the AS5600 continuously and actively pushes a line
    over serial whenever the angle changes more than 1 degree, instead of
    the earlier MPU6050 request/response scheme. One-way (Wemos -> ESP32)
    now, no polling needed. README updated to match.
2026-09-17 Reorganize firmware under software/, add spool2spool-esp32 for the port
    software/ now mirrors hardware/: spool2spool-arduino (the working Uno
    sketch, renamed to match its folder per Arduino IDE convention),
    WemosAngleSensor (unchanged), and a new empty spool2spool-esp32 folder
    for the ESP32 (30-pin devkit) + I2C LCD port that's starting next.
2026-09-18 Add ESP32 main controller + no-LCD debug sketch, drop Arduino from README
    Motor 1/2 control, buttons, and Serial2-based angle intake from the Wemos
    D1 mini node ported to the ESP-WROOM-32 with a 20x4 I2C LCD. Includes a
    debug variant that routes all display output to Serial for bench testing
    without a working LCD. README now documents the ESP32 as the primary
    firmware with no remaining references to the Arduino Uno version.
2026-09-18 Add hardware design files: KiCad schematic, angle-sensor housing, encoder disk
    [AS5600.SLDPRT, ASSEMBLY-1002_ASM_1_ASM.SLDASM, ASSEMBLY-1225_ASM_1_ASM.SLDASM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]
2026-09-19 Update ESP32/Arduino firmware and README; add LCD bezel CAD, LCD MVP sketch, serial plot tool
    [2 way header curved.SLDPRT, 20x4 LCD.SLDPRT, 4 way header curved.SLDPRT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]
2026-09-19 Remove Arduino sketch
2026-09-19 Shorten LCD labels, align setpoints, add cable color column, update bezel CAD
    [bezel-screen.3MF, bezel-screen.SLDASM, screen-bezel.SLDPRT]
2026-09-24 Add WiFi dashboard/OTA (with AP fallback), motor % on LCD, EN 60204-1 wire colors and Machine Directive TODO
    - LCD now shows motor 1/2 drive level as a percentage under the mode line
    - ESP32 sketch adds a WiFi dashboard + ElegantOTA for firmware updates once
    USB isn't reachable (external 5V supply), falling back to its own AP if no
    configured network is found; dashboard HTML moved to its own header to
    avoid Arduino's ctags prototype generator mangling embedded JS
    - README: add a suggested EN 60204-1 wire color column to the wiring tables,
    and a Machine Directive/CE compliance section on the missing hardware
    emergency stop, tracked in the TODO list
    [spool2spool-esp32.ino]
2026-09-24 Fix motor 2 speed-loop bugs and add dashboard/OTA UI polish
    Firmware (spool2spool-esp32.ino):
    - Debounce the hall sensor (minPulseIntervalMicros) and add an RPM
    plausibility filter (maxPlausibleRpmJumpFactor, self-unsticking after
    one held cycle) to reject EMI/noise-driven phantom pulses without
    risking a permanent lock onto a stale reading
    - Fix integer-truncation bug that silently discarded small speed-loop
    corrections below 1 PWM count, causing a permanent steady-state
    offset (motor2PWMF float accumulator, rounded only at the PWM write)
    - Smooth pot 2's target-speed setpoint (pot2Filtered EMA) instead of
    reading it raw every loop
    - Separate, lighter RPM averaging for the contr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
    [spool2spool-esp32.ino]
